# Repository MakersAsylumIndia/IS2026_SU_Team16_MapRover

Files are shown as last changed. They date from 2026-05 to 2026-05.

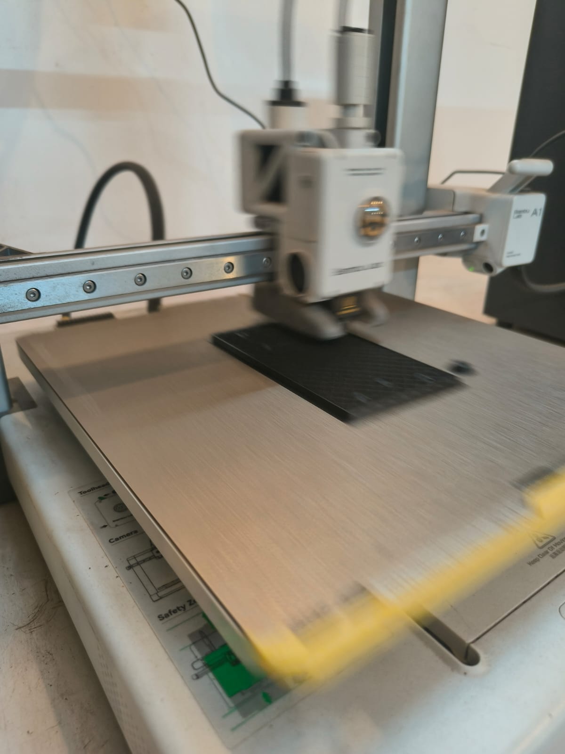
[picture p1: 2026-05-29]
Photos_Videos/Images/3dPrintingPlate.jpeg

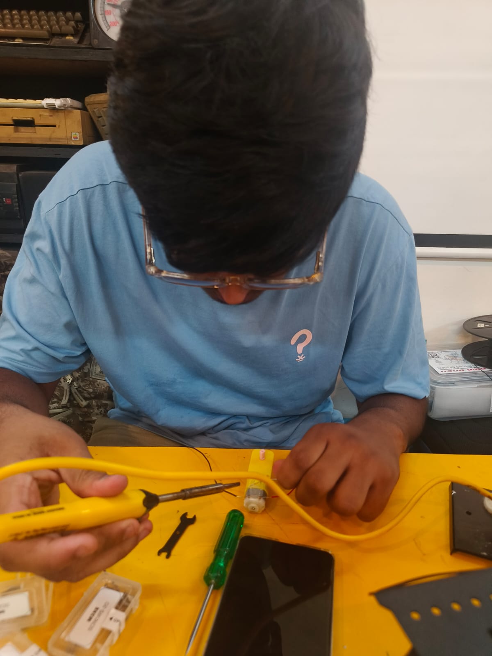
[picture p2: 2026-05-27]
Photos_Videos/Images/soldering.jpeg

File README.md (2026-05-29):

# IS2026 Spring - NAME OF PROJECT

Describe the project.
Describe what are the contents of each folder - CODE, CAD, Electronics etc

## License

Licenses

<a href="LICENSE.md">Open Source Licenses Facts</a>

#### Hardware
CERN Open Hardware License Version 2 - Strongly Reciprocal ([CERN-OHL-S-2.0](https://spdx.org/licenses/CERN-OHL-S-2.0.html)).

#### Software
MIT open source [license](http://opensource.org/licenses/MIT).

#### Documentation:
<br />This work is licensed under a <a rel="license" href="http://creativecommons.org/licenses/by/4.0/">Creative Commons Attribution 4.0 International License</a>.

---

## 📬 Contact/Team

> _List team members and contact emails or GitHub profiles._
[@anool](https://github.com/Anool)
[sresht](mailto:sreshtchandgotia@gmail.com)
[@aayan]
> ---

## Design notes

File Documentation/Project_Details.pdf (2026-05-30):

# Project Details — MapRover

## What Is MapRover?

MapRover is a teleoperated rover built on a 6-wheel rocker-bogie chassis, with the front and rear 4 wheels driven, that builds a real-time 2D map of any indoor environment as you drive it around. The operator controls the rover remotely through a browser on their phone or laptop. As the rover moves, a spinning laser sensor (LiDAR) continuously scans the surroundings and the onboard computer assembles a live map — the same principle behind how robot vacuums "see" their rooms, but with far more precision.

The project is inspired by NASA's Mars rovers, specifically the rocker-bogie suspension system, which allows the rover to roll over uneven terrain without tipping. The same mechanism is used here.

## The Problem It Solves

Exploring unknown or restricted indoor spaces — collapsed structures, large warehouses, hazardous rooms — is risky for humans. Professional mapping equipment is expensive. MapRover offers an affordable, remotely operated alternative that can navigate a space and generate a usable map in real time.

## System Architecture

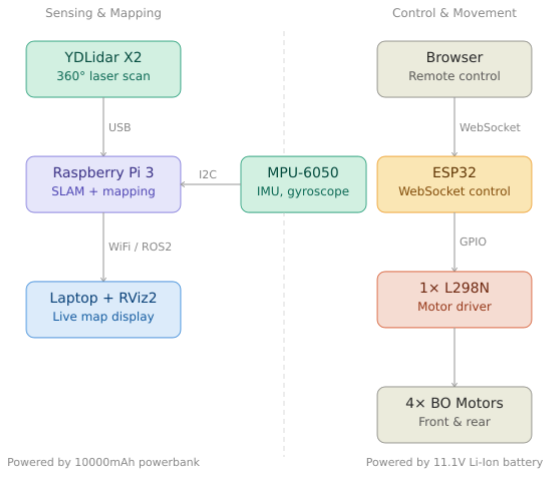
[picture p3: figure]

Movement layer (ESP32): The ESP32 microcontroller hosts its own WiFi access point. The operator connects to it and opens a browser page with directional buttons. Commands are sent over WebSockets to the ESP32, which drives a single L298N motor driver module — OUT1 and OUT2 (Channel A) control the right-side 2 motors (front and rear right), and OUT3 and OUT4 (Channel B) control the left-side 2 motors (front and rear left). The 2 middle wheels on the rocker-bogie arms are passive and not driven.

Mapping layer (Raspberry Pi 3): The Raspberry Pi 3 runs ROS2 Humble on Ubuntu Server
22.04. It reads laser scan data from the YDLidar X2 (connected over USB) and runs the slam_toolbox package to build a 2D map in real time. An MPU-6050 IMU connected to the Pi over I2C feeds rotation data into a robot_localization EKF node, which corrects the map during sharp turns and prevents distortion.

Visualization: The laptop runs RViz2 and connects to the Pi over the same WiFi network using ROS2's built-in multi-machine communication (ROS_DOMAIN_ID). The live map is displayed on the laptop as the rover moves.

## Hardware

Component | Purpose | Quantity
ROVER 6WD BO60 Chassis Kit | Base chassis, rocker-bogie suspension, 6x BO60 motors, wheels | 1
YDLidar X2 | 360° laser scanner for mapping | 1
Raspberry Pi 3 | Mapping computer, runs ROS2 and slam_toolbox | 1
ESP32 | Motor controller, hosts WiFi and WebSocket server | 1
L298N Motor Driver Module | Channel A (OUT1+OUT2) drives right 2 motors, Channel B (OUT3+OUT4) drives left 2 motors | 1
MPU-6050 IMU | Gyroscope for rotation correction during mapping | 1
11.1V 5000mAh 3S Li-Ion Battery | Powers the motors via L298N | 1
10000mAh Powerbank | Powers the Raspberry Pi via USB | 1
Aluminium Heatsinks | Prevents Raspberry Pi from throttling | 1 set
M3 Nylon Standoffs | Mounts PCBs safely above the metal chassis | As needed
XT60H Connector | Battery connection point | 1

Component | Purpose | Quantity
Micro SD Card | OS storage for Raspberry Pi | 1
Jumper wires, silicone wire 20AWG | All electrical connections | As needed
Zip ties, double-sided tape | Cable management and component mounting | As needed

The SG90 servo and ultrasonic sensor included in the rover kit are not used in this version of the project. The 2 middle motors on the rocker-bogie arms are also not connected to the driver — only the 4 front and rear motors are driven.

## Software Stack

Software | Where it runs | Purpose
Ubuntu Server 22.04 LTS (64-bit) | Raspberry Pi | Operating system required for ROS2 Humble
ROS2 Humble | Raspberry Pi | Robot middleware — connects all software components
slam_toolbox (async) | Raspberry Pi | Builds the 2D map from LiDAR scan data
ydlidar_ros2_driver | Raspberry Pi | Reads data from the YDLidar X2
robot_localization (EKF) | Raspberry Pi | Fuses IMU data for accurate rotation tracking
RViz2 | Windows Laptop (via WSL2) | Visualizes the live map
Arduino IDE / ESP32 firmware | ESP32 | WebSocket server + motor control logic

## Key Design Decisions

Why two separate controllers (ESP32 + Raspberry Pi)? The Raspberry Pi handles computationally heavy work (SLAM, LiDAR processing). Running motor control on the same board would introduce timing conflicts and slow down the mapping. The ESP32 handles motor control independently and reliably at low latency.

Why ESP32 instead of Arduino Nano for motor control? The original plan used the Arduino Nano, but the ESP32 was used because it has built-in WiFi, allowing wireless control without any additional modules. The operator does not need a physical connection to the rover.

Why a powerbank for the Pi instead of the main battery? Motors create large voltage spikes when starting and stopping. Powering the Pi from the same battery as the motors risks corrupting the SD card or crashing the Pi. The powerbank provides clean, stable power completely isolated from the motor circuit.

Why EKF with IMU? Without the IMU, slam_toolbox relied only on LiDAR scan matching for its rotation estimate. During sharp turns, the scan matching briefly fails (the environment looks ambiguous) and the map tears diagonally. The MPU-6050's gyroscope gives an independent, accurate rotation reading that the EKF fuses in to prevent this.

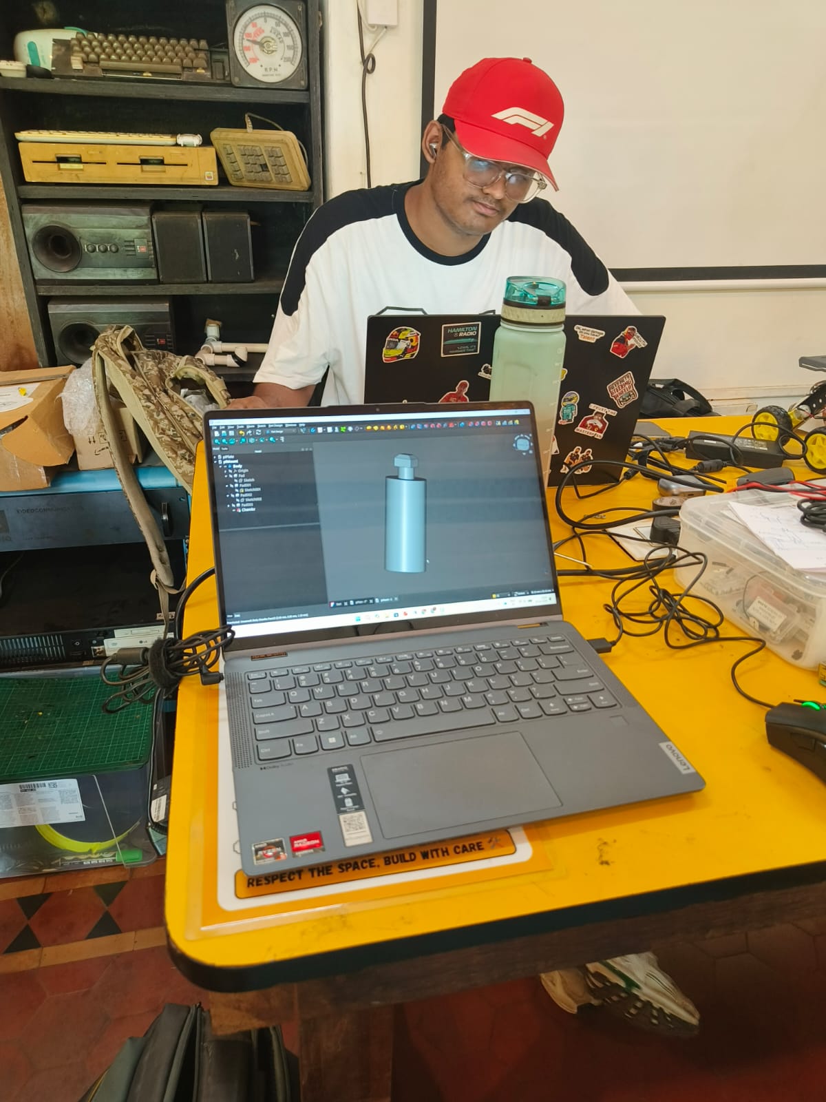
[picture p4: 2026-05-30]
Photos_Videos/Images/shaftDesigning.jpeg

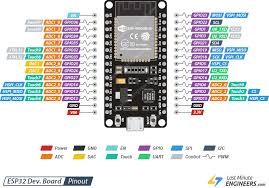
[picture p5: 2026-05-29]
Electronics/esp32Pinout.jpg

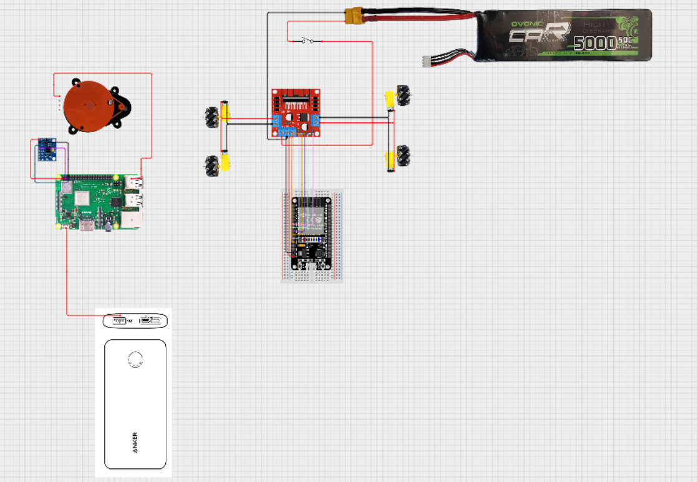
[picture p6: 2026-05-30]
Electronics/circuit_image_withesp32.png

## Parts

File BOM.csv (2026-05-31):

Name of the Material/Component | Quantity | Reference Link | Additional Note
ROVER 6WD BO60 Chassis Kit | 1 | https://www.amrobotics.in/products/rover-6wd-bo60-chassis-kit | Includes 6x BO60 60RPM motors, wheels, rocker-bogie frame and assembly manual. SG90 servo and ultrasonic sensor included in kit are not used in this project.
YDLidar X2 | 1 | https://probots.co.in/ydlidar-x2-triangulation-series-distance-sensor-rangefinder-8m-360-uart.html | 360 degree laser scanner with 8m range. Connects to Raspberry Pi via USB. Must be mounted at highest point of rover with clear 360 degree view.
Raspberry Pi 3 Model B | 1 | https://robu.in/product/raspberry-pi-3-model-b-plus-starter-kit/ | Main mapping computer running Ubuntu Server 22.04 and ROS2 Humble. Requires 16GB+ microSD card. Apply heatsinks before first boot.
ESP32 Dev Module | 1 | https://robu.in/product/esp32-38pin-development-board-wifibluetooth-ultra-low-power-consumption-dual-core/ | Motor controller. Hosts its own WiFi access point and WebSocket server for browser-based rover control.
L298N Dual H-Bridge Motor Driver | 1 | https://robu.in/product/l298n-dual-h-bridge-dc-stepper-motor-driver-controller-module/ | Channel A (OUT1+OUT2) drives right 2 motors. Channel B (OUT3+OUT4) drives left 2 motors. Connect ESP32 GND to L298N GND.
MPU-6050 IMU Module | 1 | https://robu.in/product/mpu-6050-triple-axis-accelerometer-and-gyro-breakout/ | 6-axis gyroscope and accelerometer. Connects to Raspberry Pi via I2C (SDA pin 3 and SCL pin 5). Must be mounted flat and level.
11.1V 5000mAh 3S Li-Ion Battery | 1 | https://robu.in/product-category/batteries/lipo-batteries/ | Powers motors via L298N. Keep completely isolated from Raspberry Pi power circuit. Secure low on chassis for lower center of gravity.
10000mAh Powerbank | 1 | https://www.amazon.in/s?k=10000mah+powerbank | Powers Raspberry Pi via USB. Must output 5V at 2.5A minimum. Using a separate powerbank prevents motor voltage spikes from corrupting the Pi.
Aluminium Heatsink Set for Raspberry Pi | 1 | https://robu.in/product-category/raspberry-pi/raspberry-pi-accessories/ | Apply largest heatsink to main processor chip and medium heatsink to USB/Ethernet controller chip before mounting Pi on chassis.
M3 Nylon Standoff Spacer Kit | 1 | https://robu.in/product-category/components/standoffs-and-spacers/ | Use to mount all PCBs above metal chassis. Never place circuit boards directly on metal chassis as it causes short circuits.
XT60H Connector Pair | 1 | https://robu.in/product/xt60h-male-female-connector-pair/ | Main battery connector. Solder to battery leads and power wires going to L298N.
MicroSD Card 32GB Class 10 | 1 | https://www.amazon.in/s?k=32gb+microsd+class+10 | OS storage for Raspberry Pi. Class 10 or U3 minimum. Faster cards reduce boot time.
USB-A to Micro-USB Cable | 2 | https://robu.in/product-category/cables-and-wires/usb-cables/ | One for Powerbank to Raspberry Pi. One for ESP32 programming via Arduino IDE. Must support data transfer not just charging.
USB-A to USB-A Cable | 1 | https://www.amazon.in/s?k=usb+a+to+usb+a+cable | Connects YDLidar X2 USB adapter board to Raspberry Pi USB port.
Silicone Wire 20AWG (Red and Black) | 1 | https://robu.in/product-category/cables-and-wires/silicone-wires/ | For motor and power connections between battery, L298N and motors.
Jumper Wires Set (M-M and M-F) | 1 | https://robu.in/product-category/cables-and-wires/jumper-wires/ | For signal connections between ESP32 and L298N. Also for MPU-6050 to Raspberry Pi I2C connections.
3D Printed Parts | 1 | https://github.com/MakersAsylumIndia/IS2026_SU_Team16_MapRover/tree/main/CAD | Custom mounts for YDLidar X2 and component brackets. STL files in the CAD folder of this repo. Print in PLA at 20% infill minimum.
Zip Ties and Double-Sided Foam Tape | 1 | https://www.amazon.in/s?k=zip+ties+double+sided+tape | For cable management and securing components to the chassis frame.

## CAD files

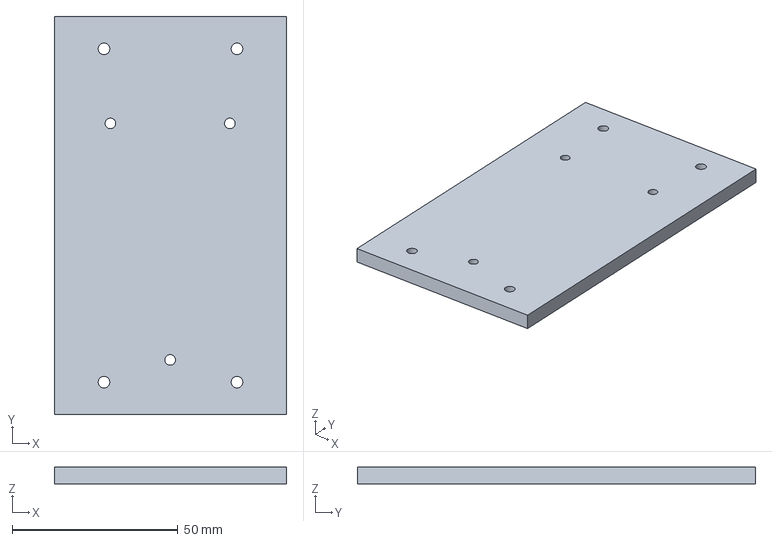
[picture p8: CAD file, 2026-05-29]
CAD/plateV1.FCStd
70.0 x 120.0 x 5.00 mm

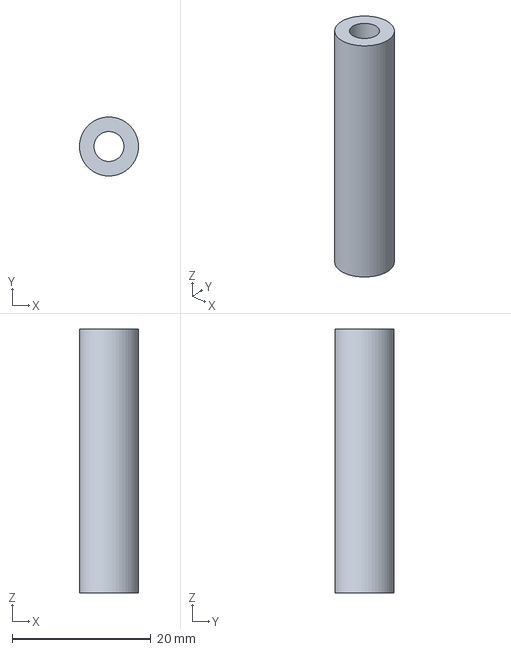
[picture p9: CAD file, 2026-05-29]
CAD/cylinderV1.FCStd
8.49 x 8.50 x 38.0 mm

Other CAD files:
CAD/piPlate.FCStd

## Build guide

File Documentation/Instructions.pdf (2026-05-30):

# Instructions — MapRover Setup Guide

This guide walks through setting up MapRover from scratch. Complete each section in order.

## Section 1: Hardware Assembly

1. Assemble the 6WD BO60 chassis following the kit's included assembly manual. Ensure all 6 motors are seated firmly and the rocker-bogie arms pivot freely on both sides.
2. Attach aluminium heatsinks to the Raspberry Pi 3 before mounting it:
- Largest heatsink → main processor chip
- Medium heatsink → USB/Ethernet controller chip
3. Mount the Raspberry Pi, ESP32, and L298N. Attach the L298N in the center using strong double sided tape. Laser cut or 3D print the plate to mount raspberry pi and use standoffs to make the attachments. Use a breadboard for mounting the ESP32 and use double sided tape to attach the breadboard. Never place circuit boards directly on the metal chassis — it causes short circuits.
4. Mount the YDLidar X2 at the highest point of the rover, at the geometric center (front-to-back and left-to-right). The laser must have a clear 360° view with no parts of the rover body blocking it. Secure it firmly — vibration corrupts scan data. 3D print the cylinders and the plate for the lidar and use long screws to connect everything.
5. Attach the MPU-6050 flat (level with the ground) and oriented so the IMU Z-axis points straight up. This is critical for accurate yaw (rotation) measurement. This attachment is to be done on the plate made for the raspberry pi. It has holes for this purpose.
6. Mount the 11.1V battery low on the chassis for a lower center of gravity. Secure the powerbank on the side or rear.

## Section 2: Wiring

For the full detailed wiring diagram with pin numbers, see /Electronics/ in the repo root.

Motor wiring:

- Right 2 motors (front-right and rear-right): wire both A terminals together → OUT1, both B terminals together → OUT2
- Left 2 motors (front-left and rear-left): wire both A terminals together → OUT3, both B terminals together → OUT4
- The 2 middle motors on the rocker-bogie arms are left unconnected

ESP32 to L298N connections:

L298N Pin | ESP32 GPIO | Function
ENA | see Code folder | Right side speed (PWM)
IN1 | see Code folder | Right direction control
IN2 | see Code folder | Right direction control
ENB | see Code folder | Left side speed (PWM)
IN3 | see Code folder | Left direction control
IN4 | see Code folder | Left direction control

Exact GPIO numbers are in the ESP32 motor control code in /Code/. Check there for the pin assignments specific to your board.

Critical: Connect ESP32 GND to the L298N GND terminal. Without a common ground, the control signals have no reference and the motors will not respond.

Power:

- 11.1V battery (positive) → rocker switch → L298N VCC
- 11.1V battery (negative) → L298N GND
- Powerbank → Raspberry Pi via USB-A to Micro-USB cable (keep completely separate from the motor circuit)

YDLidar X2: Connect to any USB port on the Raspberry Pi using the included USB adapter cable.

MPU-6050 to Raspberry Pi (I2C):

MPU-6050 Pin | Raspberry Pi Physical Pin
VCC | Pin 1 (3.3V)
GND | Pin 6 (GND)
SDA | Pin 3 (GPIO 2)
SCL | Pin 5 (GPIO 3)

## Section 3: Raspberry Pi OS and ROS2 Setup

3.1 — Flash Ubuntu Server 22.04 LTS (64-bit) to the microSD card using Raspberry Pi Imager (use a 16GB or larger card). In the imager's OS Customisation settings before writing: set hostname to mapRover, enable SSH, set a username and password, and enter your WiFi credentials.

3.2 — SSH into the Pi after first boot:

ssh <your-username>@mapRover.local

If mapRover.local doesn't resolve, find the Pi's IP address from your router's connected devices list and use that instead: ssh
<your-username>@<ip-address>

3.3 — Install ROS2 Humble:

sudo apt update && sudo apt upgrade -y

sudo apt install -y software-properties-common curl

sudo curl -sSL https://raw.githubusercontent.com/ros/rosdistro/master/ros.key \

-o /usr/share/keyrings/ros-archive-keyring.gpg

echo "deb [arch=$(dpkg --print-architecture) \

signed-by=/usr/share/keyrings/ros-archive-keyring.gpg] \

http://packages.ros.org/ros2/ubuntu jammy main" \

| sudo tee /etc/apt/sources.list.d/ros2.list > /dev/null

sudo apt update

sudo apt install -y ros-humble-ros-base python3-colcon-common-extensions

echo "source /opt/ros/humble/setup.bash" >> ~/.bashrc

source ~/.bashrc

3.4 — Install required packages:

sudo apt install -y \

python3-pip \

cmake \

ros-humble-slam-toolbox \

ros-humble-robot-localization \

ros-humble-tf-transformations \

i2c-tools python3-smbus

pip3 install pyserial smbus2

3.5 — Add user to device access groups:

This is required so your user can access the YDLidar (USB serial) and MPU-6050 (I2C) without running commands as root.

sudo usermod -aG dialout $USER

sudo usermod -aG i2c $USER

Log out and back in (or reboot) for the group changes to take effect.

3.6 — Enable I2C for the MPU-6050:

sudo nano /boot/firmware/config.txt

# Add at the bottom: dtparam=i2c_arm=on

echo "i2c-dev" | sudo tee -a /etc/modules

sudo reboot

After reboot, verify the IMU is detected:

i2cdetect -y 1

# You should see address 0x68 in the grid

3.7 — Create the ROS2 workspace:

This step is required before cloning any packages. Without it, steps 3.8 and 3.9 will fail because the directory doesn't exist.

mkdir -p ~/ros2_ws/src

cd ~/ros2_ws

colcon build

echo "source ~/ros2_ws/install/setup.bash" >> ~/.bashrc

source ~/.bashrc

3.8 — Install the YDLidar ROS2 driver:

cd ~/ros2_ws/src

git clone https://github.com/YDLIDAR/ydlidar_ros2_driver.git

cd ~/ros2_ws

colcon build --symlink-install --packages-select ydlidar_ros2_driver

source ~/.bashrc

After building, install the YDLidar udev rules. These give the device a consistent name (/dev/ydlidar) so the launch file always finds it regardless of which USB port it is plugged into:

cd ~/ros2_ws/src/ydlidar_ros2_driver

sudo chmod 0777 startup/initenv.sh

sudo ./startup/initenv.sh

Reconnect the YDLidar USB cable, then verify the device is visible:

ls /dev/ydlidar

# Should print: /dev/ydlidar

3.9 — Clone and build the maprover_core package:

cd ~/ros2_ws/src

git clone https://github.com/MakersAsylumIndia/IS2026_SU_Team16_MapRover.gitmaprover_core

cd ~/ros2_ws

colcon build --symlink-install --packages-select maprover_core

source ~/.bashrc

3.10 — Understanding the configuration files:

All config files live inside ~/ros2_ws/src/maprover_core/config/. You do not need to edit these to run the project as-is, but understanding them is important if you want to adapt the project to different hardware or tune the mapping behaviour.

mapping.launch.py Location: maprover_core/launch/mapping.launch.py

This is the single entry point that starts everything. It launches five things in order:

1. The YDLidar driver node (with the lidar params file)
2. The IMU publisher node (reads MPU-6050 and publishes to /imu/data)
3. The static transform publishers (defines the physical positions of sensors on the rover)
4. The robot_localization EKF node (with the EKF params file)

5. The slam_toolbox async mapping node (with the slam params file)

If any of these fail to start, run ros2 launch maprover_core mapping.launch.py
--debug to see which node is throwing errors.

ydlidar_params.yaml Location: maprover_core/config/ydlidar_params.yaml

Tells the YDLidar ROS2 driver how to communicate with the X2 sensor.

Key parameters and what to change:

port: /dev/ydlidar | # Device name — only change if udev rules weren't installed
baudrate: 115200 | # Fixed for X2, do not change
lidar_type: 1 | # 1 = TYPE_TRIANGLE, correct for X2
frame_id: laser_frame | # Must match the TF static transform (see below)
angle_min: -3.14159 | # Full 360° scan, -π to π

angle_max: 3.14159

range_min: 0.10 | # Minimum valid scan distance in metres
range_max: 8.0 | # X2 maximum range is 8m

If the lidar appears to scan only half the room or produces a mirrored map, check angle_min/angle_max and the physical mounting orientation.

ekf_params.yaml Location: maprover_core/config/ekf_params.yaml

Configures the robot_localization Extended Kalman Filter. The EKF fuses the IMU's gyroscope data to produce a stable odom → base_link transform for slam_toolbox to use. Without this, sharp turns cause the map to tear because slam_toolbox has no reliable rotation reference between scans.

Key parameters and what to change:

frequency: 30 | # How often the EKF publishes, in Hz
imu0: /imu/data | # Topic published by the IMU node — must match exactly
imu0_config: [false, false, false, # x, y, z position | — not used
false, false, true, # roll, pitch, yaw | — yaw (rotation) is used

false, false, false, # vx, vy, vz velocity — not used

false, false, true, # vroll, vpitch, vyaw — yaw rate is used

false, false, false] # ax, ay, az accel — not used

odom_frame: odom

base_link_frame: base_link

world_frame: odom

The imu0_config matrix is the most important part. Each true entry tells the EKF to use that measurement from the IMU. For this project only yaw (rotation around Z axis) and yaw rate matter — position and linear velocity from the IMU are too noisy to be useful.

If the map drifts or rotates incorrectly, the first thing to check is whether /imu/data is being published (ros2 topic echo /imu/data) and whether the covariance values in the IMU message are set correctly by the IMU node.

slam_toolbox_params.yaml Location: maprover_core/config/slam_toolbox_params.yaml

Configures the slam_toolbox async mapping node. This controls map resolution, how often the map updates, and how far the rover must move before a new scan is processed.

Key parameters and what to change:

mode: mapping | # 'mapping' builds a new map; 'localization' uses a saved one
resolution: 0.05 | # Map resolution in metres per pixel (0.05 = 5cm per cell)
| # Lower = more detailed map but slower on Pi 3

max_laser_range: 8.0 # Should match the lidar's range_max in ydlidar_params.yaml

minimum_travel_distance: 0.3 # Rover must move 0.3m before processing a new scan

minimum_travel_heading: 0.3 # Or rotate 0.3 radians (~17°)

# Increase these if the Pi is struggling to keep up

map_update_interval: 1.0 # Seconds between map publishes to RViz2

# Increase if map updates are causing lag

odom_frame: odom

base_frame: base_link

map_frame: map

scan_topic: /scan # Must match what the YDLidar driver publishes

If the map looks blocky, lower the resolution. If the Pi is running hot or the map lags, increase minimum_travel_distance and map_update_interval.

imu_publisher.py Location: maprover_core/maprover_core/imu_publisher.py

This is a custom ROS2 node because the MPU-6050 has no official ROS2 driver. It reads raw gyroscope and accelerometer data from the sensor over I2C using smbus2, converts it to standard SI units, and publishes a sensor_msgs/Imu message to /imu/data at 30Hz.

What it does:

- Reads gyroscope registers (rotation rate in radians/second around X, Y, Z)
- Reads accelerometer registers (linear acceleration in m/s²)
- Fills in the orientation_covariance, angular_velocity_covariance, and
linear_acceleration_covariance fields — these tell the EKF how much to trust the sensor
- Publishes with frame_id: imu_link

If the IMU node is running but the map still tears on turns, the covariance values in this file may need tuning — lower covariance values tell the EKF to trust the IMU more.

Static Transform Publishers (TF tree)

The TF (Transform) tree defines the physical geometry of the rover — where each sensor is mounted relative to the robot's center. slam_toolbox uses this to know where the laser scan originated in space. Without a correct TF tree, the mapping will fail silently or produce a distorted map.

The full TF chain for this project is:

map → odom → base_link → laser_frame

→ imu_link

- map → odom is published live by slam_toolbox
- odom → base_link is published live by the EKF node
- base_link → laser_frame is a static transform defined in the launch file
- base_link → imu_link is a static transform defined in the launch file

The static transforms look like this in the launch file:

Node(

package='tf2_ros',

executable='static_transform_publisher',

arguments=['0', '0', '0.1', '0', '0', '0', 'base_link', 'laser_frame']

# x=0, y=0, z=0.1m above base, no rotation

)

If the LiDAR is remounted at a different height or position on the rover, update the z value (height in metres) in this static transform. Getting this wrong does not crash anything but subtly corrupts the map geometry.

To verify the full TF tree is correctly connected at runtime:

ros2 run tf2_tools view_frames

This generates a frames.pdf showing the complete tree. Every frame must be connected — any gap in the chain means mapping will not work.

## Section 4: ESP32 Setup

4.1 — Install Arduino IDE on your computer from https://www.arduino.cc/en/software

4.2 — Add ESP32 board support:

- File → Preferences → Additional Board Manager URLs: https://espressif.github.io/arduino-esp32/package_esp32_index.jso n
- Tools → Board → Boards Manager → search "esp32" → install "esp32 by Espressif Systems" (version 3.0 or newer)

4.3 — Install required libraries:

- Sketch → Include Library → Manage Libraries
- Install: ESPAsyncWebServer and AsyncTCP

4.4 — Flash the ESP32 motor control code:

- Open /Code/ESP32_motor_control/ from this repo in Arduino IDE
- Select board: Tools → Board → esp32 → "ESP32 Dev Module"
- Select the correct COM port under Tools → Port
- Upload the code

## Section 5: Laptop Setup (RViz2 via WSL2 on Windows)

5.1 — Install WSL2 on Windows (if not already installed):

wsl --install

Restart your computer. Open the Ubuntu app from the Start menu and complete the initial username/password setup.

5.2 — Check your Windows version for GUI support:

RViz2 is a graphical application. How it works depends on your Windows version:

- Windows 11: WSLg is built in and handles GUI apps automatically. No extra setup needed.
- Windows 10: WSL2 does not include GUI support. You must install VcXsrv (free X server) from https://sourceforge.net/projects/vcxsrv/. After installing, launch XLaunch, choose "Multiple Windows", set Display number to 0, and tick "Disable access control". Then in WSL2 run:
echo "export DISPLAY=$(cat /etc/resolv.conf | grep nameserver | awk '{print $2}'):0" >>
~/.bashrc

source ~/.bashrc

5.3 — Install ROS2 Humble in WSL2 following the same steps as Section 3.3 above.

5.4 — Install RViz2:

sudo apt install -y ros-humble-rviz2

5.5 — Create the ROS2 workspace in WSL2:

mkdir -p ~/ros2_ws/src

cd ~/ros2_ws

colcon build

echo "source ~/ros2_ws/install/setup.bash" >> ~/.bashrc

source ~/.bashrc

5.6 — Fix WSL2 networking for ROS2 cross-machine discovery:

By default, WSL2 uses a virtual NAT network which blocks the multicast packets that ROS2 uses to discover nodes on other machines. Without this fix, the laptop will never see topics from the Raspberry Pi even if both are on the same WiFi.

On Windows 11: Enable mirrored networking mode. Open (or create) C:\Users\<YourUsername>\.wslconfig in Notepad and add:

[wsl2]

networkingMode=mirrored

Then restart WSL2 from PowerShell: wsl --shutdown, then reopen Ubuntu.

On Windows 10: Mirrored mode is not available. Use CycloneDDS with a manual peer config. Install it in WSL2:

sudo apt install -y ros-humble-rmw-cyclonedds-cpp

echo "export RMW_IMPLEMENTATION=rmw_cyclonedds_cpp" >> ~/.bashrc

Create a CycloneDDS config file:

nano ~/cyclonedds_pi.xml

Add the following, replacing <PI_IP_ADDRESS> with your Raspberry Pi's actual IP:

<CycloneDDS>

<Domain>

<Discovery>

<Peers>

<Peer Address="<PI_IP_ADDRESS>"/>

</Peers>

</Discovery>

</Domain>

</CycloneDDS>

Then add to .bashrc:

echo "export CYCLONEDDS_URI=file://$HOME/cyclonedds_pi.xml" >> ~/.bashrc

source ~/.bashrc

Apply the same CycloneDDS setup on the Raspberry Pi as well.

5.7 — Set the ROS domain ID (must match the Pi):

echo "export ROS_DOMAIN_ID=42" >> ~/.bashrc

echo "export ROS_LOCALHOST_ONLY=0" >> ~/.bashrc

source ~/.bashrc

On the Raspberry Pi, set the same:

echo "export ROS_DOMAIN_ID=42" >> ~/.bashrc

echo "export ROS_LOCALHOST_ONLY=0" >> ~/.bashrc

source ~/.bashrc

Both machines must be on the same WiFi network. After this, they will automatically discover each other's ROS2 topics. Verify it is working by running ros2 topic list in WSL2 while the Pi's mapping stack is running — you should see /map, /scan, and /imu/data in the list.

## Section 6: Running the Rover

Step 1 — Start mapping on the Raspberry Pi:

ros2 launch maprover_core mapping.launch.py

This launches the YDLidar driver, the IMU publisher, the EKF node, and slam_toolbox together.

Step 2 — Open RViz2 on your laptop (WSL2):

export DISPLAY=:0

rviz2

In RViz2:

- Set Fixed Frame to map
- Add → Map → Topic: /map
- Add → LaserScan → Topic: /scan

Step 3 — Connect to the rover's WiFi:
- Connect your phone or laptop to the ESP32's WiFi hotspot (network name and password are in the ESP32 code)
- Open a browser and go to 192.168.4.1
- Drive the rover — the map builds live as you move

Optional — Xbox controller: Connect the controller via Bluetooth or USB to the device running the browser. The web interface supports Xbox controller input via the browser Gamepad API.

Saving the map: Once you have mapped an area, save it with:

ros2 service call /slam_toolbox/save_map slam_toolbox/srv/SaveMap "{name: {data: '/home/<username>/my_map'}}"

This creates my_map.pgm and my_map.yaml.

## Known Issues and Notes

- The Raspberry Pi 3 is resource-limited for SLAM. Expect the map update rate to be around 1 second. If the system becomes sluggish, ensure no unnecessary processes are running.
- RViz2 on WSL2 may require export DISPLAY=:0 or export DISPLAY=:0.0 before
launching, depending on your WSL2 version.
- The YDLidar X2 must be connected before the launch file is run, or the driver node will fail to start.
- If the map tears diagonally during sharp turns, check that the IMU publisher and EKF nodes are running correctly (ros2 topic list should show /imu/data and an odom → base_link transform should exist in the TF tree).
- If the motor driver shows abnormal behaviour (such as one side not rotating in one of the directions) make sure to change your jumper wires before anything else.
- With the middle two wheels not turning, resistance increases so for higher speed movement try using two motor drivers. This however would not help from the mapping perspective as the quality of the map is better the slower the rover moves.

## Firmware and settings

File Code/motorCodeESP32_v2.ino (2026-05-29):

#include <WiFi.h>
#include <ESPAsyncWebServer.h>
#include <AsyncTCP.h>

const char* ssid     = "Jiofiber4g";
const char* password = "jyoti123";

AsyncWebServer server(80);
AsyncWebSocket ws("/ws");

// Motor A - right
const int ENA = 14;
const int IN1 = 27;
const int IN2 = 26;

// Motor B - left
const int ENB = 32;
const int IN3 = 25;
const int IN4 = 33;

const int PWM_FREQ = 1000;
const int PWM_RES  = 8;

// ─── Motor Functions (accept speed) ───────────────────────────

void moveForward(int spd) {
  ledcWrite(ENA, spd); ledcWrite(ENB, spd);          // Set speed FIRST
  digitalWrite(IN1, LOW);  digitalWrite(IN2, HIGH);
  digitalWrite(IN3, LOW);  digitalWrite(IN4, HIGH);
}

void moveBackward(int spd) {
  ledcWrite(ENA, spd); ledcWrite(ENB, spd);
  digitalWrite(IN1, HIGH); digitalWrite(IN2, LOW);
  digitalWrite(IN3, HIGH); digitalWrite(IN4, LOW);
}

void turnLeft(int spd) {
  ledcWrite(ENA, spd); ledcWrite(ENB, spd);
  digitalWrite(IN1, LOW);  digitalWrite(IN2, HIGH);  // Right: forward
  digitalWrite(IN3, HIGH); digitalWrite(IN4, LOW);   // Left: backward
}

void turnRight(int spd) {
  ledcWrite(ENA, spd); ledcWrite(ENB, spd);
  digitalWrite(IN1, HIGH); digitalWrite(IN2, LOW);   // Right: backward
  digitalWrite(IN3, LOW);  digitalWrite(IN4, HIGH);  // Left: forward
}

void stopMotors() {
  digitalWrite(IN1, LOW); digitalWrite(IN2, LOW);
  digitalWrite(IN3, LOW); digitalWrite(IN4, LOW);
  ledcWrite(ENA, 0); ledcWrite(ENB, 0);              // Kill PWM AFTER pins
}
// ─── WebSocket Handler ─────────────────────────────────────────
// Commands: "F180", "B110", "L200", "R200", "S"
// First char = direction, rest = speed value

void onWsEvent(AsyncWebSocket* server, AsyncWebSocketClient* client,
               AwsEventType type, void* arg, uint8_t* data, size_t len) {
  if (type == WS_EVT_DATA) {
    String msg = "";
    for (size_t i = 0; i < len; i++) msg += (char)data[i];

    char cmd = msg[0];
    int spd = 150; // fallback default
    if (msg.length() > 1) {
      spd = constrain(msg.substring(1).toInt(), 80, 255);
    }

    if      (cmd == 'F') moveForward(spd);
    else if (cmd == 'B') moveBackward(spd);
    else if (cmd == 'L') turnLeft(spd);
    else if (cmd == 'R') turnRight(spd);
    else if (cmd == 'S') stopMotors();
  }
}

// ─── HTML Page ─────────────────────────────────────────────────

const char* htmlPage =
  "<!DOCTYPE html><html>"
  "<head>"
  "<title>Rover Control</title>"
  "<meta name='viewport' content='width=device-width, initial-scale=1'>"
  "<style>"
  "body{display:flex;flex-direction:column;align-items:center;"
  "font-family:sans-serif;background:#111;color:white;padding-top:20px;}"

  // Direction buttons
  "button{width:80px;height:80px;font-size:28px;margin:8px;"
  "border-radius:12px;border:none;background:#333;color:white;cursor:pointer;"
  "-webkit-tap-highlight-color:transparent;}"
  "button:active{background:#555;}"
  ".row{display:flex;}"

  // Speed slider
  "#speed-wrap{margin-top:24px;width:260px;text-align:center;}"
  "#speed-label{font-size:14px;color:#aaa;margin-bottom:8px;}"
  "#speed-val{font-size:22px;font-weight:bold;color:#4CAF50;}"
  "input[type=range]{width:100%;accent-color:#4CAF50;"
  "-webkit-appearance:none;height:8px;border-radius:4px;"
  "background:#333;outline:none;margin-top:8px;}"
  "input[type=range]::-webkit-slider-thumb{"
  "-webkit-appearance:none;width:24px;height:24px;"
  "border-radius:50%;background:#4CAF50;cursor:pointer;}"

  "#status{font-size:13px;color:#888;margin-top:16px;}"
  "</style></head>"
  "<body>"
  "<h2>Rover Control</h2>"

  "<div class='row'>"
  "<button onmousedown=\"sendDir('F')\" onmouseup=\"send('S')\""
  "        ontouchstart=\"sendDir('F')\" ontouchend=\"send('S')\">&#9650;</button>"
  "</div>"
  "<div class='row'>"
  "<button onmousedown=\"sendDir('L')\" onmouseup=\"send('S')\""
  "        ontouchstart=\"sendDir('L')\" ontouchend=\"send('S')\">&#9664;</button>"
  "<button onmousedown=\"send('S')\" onmouseup=\"send('S')\""
  "        ontouchstart=\"send('S')\" ontouchend=\"send('S')\">&#9632;</button>"
  "<button onmousedown=\"sendDir('R')\" onmouseup=\"send('S')\""
  "        ontouchstart=\"sendDir('R')\" ontouchend=\"send('S')\">&#9654;</button>"
  "</div>"
  "<div class='row'>"
  "<button onmousedown=\"sendDir('B')\" onmouseup=\"send('S')\""
  "        ontouchstart=\"sendDir('B')\" ontouchend=\"send('S')\">&#9660;</button>"
  "</div>"

  // Speed slider — goes from 80 (min motors can spin) to 255 (full)
  "<div id='speed-wrap'>"
  "<div id='speed-label'>Speed: <span id='speed-val'>150</span></div>"
  "<input type='range' id='slider' min='80' max='255' value='150'"
  "  oninput=\"document.getElementById('speed-val').innerText=this.value\">"
  "</div>"

  "<p id='status'>Connecting...</p>"

  "<script>"
  "let ws;"
  "function connect(){"
  "  ws = new WebSocket('ws://'+location.host+'/ws');"
  "  ws.onopen = ()=>document.getElementById('status').innerText='Connected ✓';"
  "  ws.onclose = ()=>{"
  "    document.getElementById('status').innerText='Disconnected. Retrying...';"
  "    setTimeout(connect,2000);"
  "  };"
  "}"

  // send() for plain messages like 'S'
  "function send(msg){"
  "  if(ws && ws.readyState===WebSocket.OPEN) ws.send(msg);"
  "}"

  // sendDir() reads current slider value and appends it to direction
  "function sendDir(dir){"
  "  let spd = document.getElementById('slider').value;"
  "  send(dir + spd);"   // e.g. "F180"
  "}"

  "connect();"
  "</script>"
  "</body></html>";

// ─── Setup ─────────────────────────────────────────────────────

void setup() {
  Serial.begin(115200);

  pinMode(IN1, OUTPUT); pinMode(IN2, OUTPUT);
  pinMode(IN3, OUTPUT); pinMode(IN4, OUTPUT);

  ledcAttach(ENA, PWM_FREQ, PWM_RES);
  ledcAttach(ENB, PWM_FREQ, PWM_RES);

  stopMotors();

  WiFi.begin(ssid, password);
  Serial.print("Connecting to WiFi");
  while (WiFi.status() != WL_CONNECTED) {
    delay(500);
    Serial.print(".");
  }
  Serial.println("\nConnected!");
  Serial.print("Open this IP in your browser: ");
  Serial.println(WiFi.localIP());

  ws.onEvent(onWsEvent);
  server.addHandler(&ws);

  server.on("/", HTTP_GET, [](AsyncWebServerRequest* request) {
    request->send(200, "text/html", htmlPage);
  });

  server.begin();
  Serial.println("Server started.");
}

// ─── Loop ──────────────────────────────────────────────────────

void loop() {
  ws.cleanupClients();
}

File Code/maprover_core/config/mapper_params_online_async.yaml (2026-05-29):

slam_toolbox:
  ros__parameters:
    use_sim_time: false
    odom_frame: odom
    map_frame: map
    base_frame: base_link
    scan_topic: /scan
    mode: mapping
    debug_logging: false
    transform_timeout: 1.0
    map_update_interval: 1.0
    resolution: 0.05
    provide_odom_frame: false
    scan_queue_size: 10
    use_scan_matching: true
    use_scan_barreling: false
    minimum_time_interval: 0.05
    tf_buffer_duration: 30.0
    max_laser_range: 8.0
    minimum_travel_distance: 0.0
    minimum_travel_heading: 0.0
    ceres_linear_solver: SPARSE_NORMAL_CHOLESKY
    ceres_preconditioner: SCHUR_JACOBI
    ceres_trust_strategy: LEVENBERG_MARQUARDT
    ceres_dogleg_type: TRADITIONAL_DOGLEG
    ceres_loss_function: None
    do_loop_closing: true
    loop_search_space_dimension: 8.0
    loop_search_minimum_chain_size: 10
    loop_match_minimum_chain_size: 10
    loop_match_maximum_variance_covariance: 3.0
    loop_match_minimum_response_coarse: 0.35
    loop_match_minimum_response_fine: 0.45

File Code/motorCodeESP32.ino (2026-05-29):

#include <WiFi.h>
#include <WebServer.h>

const char* ssid     = "Jiofiber4g";
const char* password = "jyoti123";

WebServer server(80);

// Motor A
const int ENA = 14;
const int IN1 = 27;
const int IN2 = 26;

// Motor B
const int ENB = 32;
const int IN3 = 25;
const int IN4 = 33;

// New ESP32 core 3.x PWM — no channels needed
const int PWM_FREQ = 1000;
const int PWM_RES  = 8;

int testSpeed = 110;

// ─── HTML Page ─────────────────────────────────────────────────
// Raw string replaced with regular string to avoid IDE issues
const char* htmlPage =
  "<!DOCTYPE html><html>"
  "<head>"
  "<title>Rover Control</title>"
  "<meta name='viewport' content='width=device-width, initial-scale=1'>"
  "<style>"
  "body{display:flex;flex-direction:column;align-items:center;"
  "font-family:sans-serif;background:#111;color:white;}"
  "button{width:80px;height:80px;font-size:28px;margin:8px;"
  "border-radius:12px;border:none;background:#333;color:white;cursor:pointer;}"
  "button:active{background:#555;}"
  ".row{display:flex;}"
  "</style></head>"
  "<body>"
  "<h2>Rover Control</h2>"
  "<div class='row'><button onclick=\"send('F')\">&#9650;</button></div>"
  "<div class='row'>"
  "<button onclick=\"send('L')\">&#9664;</button>"
  "<button onclick=\"send('S')\">&#9632;</button>"
  "<button onclick=\"send('R')\">&#9654;</button>"
  "</div>"
  "<div class='row'><button onclick=\"send('B')\">&#9660;</button></div>"
  "<script>"
  "function send(cmd){fetch('/cmd?v='+cmd);}"
  "</script>"
  "</body></html>";

// ─── Motor Functions ───────────────────────────────────────────

void moveForward() {
  digitalWrite(IN1, HIGH); digitalWrite(IN2, LOW);
  ledcWrite(ENA, testSpeed);                        // New API: write directly to pin
  digitalWrite(IN3, HIGH); digitalWrite(IN4, LOW);
  ledcWrite(ENB, testSpeed);
}

void moveBackward() {
  digitalWrite(IN1, LOW); digitalWrite(IN2, HIGH);
  ledcWrite(ENA, testSpeed);
  digitalWrite(IN3, LOW); digitalWrite(IN4, HIGH);
  ledcWrite(ENB, testSpeed);
}

void turnLeft() {
  digitalWrite(IN1, LOW); digitalWrite(IN2, HIGH);
  ledcWrite(ENA, testSpeed);
  digitalWrite(IN3, HIGH); digitalWrite(IN4, LOW);
  ledcWrite(ENB, testSpeed);
}

void turnRight() {
  digitalWrite(IN1, HIGH); digitalWrite(IN2, LOW);
  ledcWrite(ENA, testSpeed);
  digitalWrite(IN3, LOW); digitalWrite(IN4, HIGH);
  ledcWrite(ENB, testSpeed);
}

void stopMotors() {
  ledcWrite(ENA, 0);
  ledcWrite(ENB, 0);
  digitalWrite(IN1, LOW); digitalWrite(IN2, LOW);
  digitalWrite(IN3, LOW); digitalWrite(IN4, LOW);
}

// ─── Setup ─────────────────────────────────────────────────────

void setup() {
  Serial.begin(115200);

  pinMode(IN1, OUTPUT); pinMode(IN2, OUTPUT);
  pinMode(IN3, OUTPUT); pinMode(IN4, OUTPUT);

  // New API: ledcAttach(pin, freq, resolution) — no channels
  ledcAttach(ENA, PWM_FREQ, PWM_RES);
  ledcAttach(ENB, PWM_FREQ, PWM_RES);

  stopMotors();

  WiFi.begin(ssid, password);
  Serial.print("Connecting to WiFi");
  while (WiFi.status() != WL_CONNECTED) {
    delay(500);
    Serial.print(".");
  }
  Serial.println("\nConnected!");
  Serial.print("Open this IP in your browser: ");
  Serial.println(WiFi.localIP());

  server.on("/", []() {
    server.send(200, "text/html", htmlPage);
  });

  server.on("/cmd", []() {
    if (server.hasArg("v")) {
      char cmd = server.arg("v")[0];
      if      (cmd == 'F') moveForward();
      else if (cmd == 'B') moveBackward();
      else if (cmd == 'L') turnLeft();
      else if (cmd == 'R') turnRight();
      else if (cmd == 'S') stopMotors();
    }
    server.send(200, "text/plain", "OK");
  });

  server.begin();
  Serial.println("Server started.");
}

// ─── Loop ──────────────────────────────────────────────────────

void loop() {
  server.handleClient();
}

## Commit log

2026-05-22 Lidar point cloud updating live in rviz. The slam_toolbox map also added. One issue in the map - remaining static.
    [mapper_params_online_async.yaml]
2026-05-28 Map being created successfully when the lidar is moved. The map makes inaccuracies when turning sharply though. That needs to be worked on next
2026-05-29 IMU sensor integrated to prevent the map from breaking while taking sharp turns.
    [mapper_params_online_async.yaml]
2026-05-29 Add files via upload
    Circuit diagram Link:
    https://app.cirkitdesigner.com/project/49e35666-c380-420f-a5c2-d60a6aeeb7ee
2026-05-31 Update BOM.csv with component details
    Added detailed BOM entries for components used in the rover project.
    [BOM.csv]
